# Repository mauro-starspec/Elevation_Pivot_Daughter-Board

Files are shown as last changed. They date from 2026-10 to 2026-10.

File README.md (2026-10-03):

# Elevation Pivot Daughter Board

KiCad 9 daughter board for the Starspec elevation/pivot controller.

## Current revision: P3

The schematic adds two isolated motor encoder interfaces while preserving both
SSI channels, two onboard 1206 thermistors, and all existing
controller functions. Port/Star names now apply
throughout the schematic, including brake, stepper, SSI, preset, and supply nets.
New signals use hierarchical labels; supplies use conventional power symbols.

One six-channel ISO7760F isolates both motor encoders' A/B/Z signals. Both
receivers share U105's 3.3 V supply from PS10; loss of PS10 disables both
feedback paths. The two 5 V encoder converters remain separate.

Device power switching belongs to external PSRB. Other systems already measure
battery voltage and device current. The P1 STR8 power/current and voltage
additions have been removed, along with the new one-shot encoder fuses and
external thermistor inputs. Existing brake current sensing is retained.

TH1 measures board temperature and TH2 the power area. Their passive dividers
use the existing U21 ADC's spare AIN2/3 inputs and U24 isolation. No extra sensor
ICs, regulator or I2C isolator are required. Temperature readings depend on the
brake supply. Firmware channel scheduling and conversion remain future work.

The PCB is unchanged and does not match the redesigned schematic. This is a
review revision, not a fabrication release. No firmware was changed.

## Open and review

Open [Elevation_Pivot_Daughter-Board.kicad_pro](Elevation_Pivot_Daughter-Board.kicad_pro)
in KiCad 9. Symbols and footprints are stored locally in the repository.

- [PROJECT_HANDOFF.md](PROJECT_HANDOFF.md): scope and next-session context.
- [SCHEMATIC_REDESIGN_P3.md](docs/SCHEMATIC_REDESIGN_P3.md): foundation review and current circuits.
- [REDESIGN_PLAN.md](docs/REDESIGN_PLAN.md): remaining review sequence.
- outputs/Pivot_Schematic_Review.pdf: local review export, ignored by Git.

Run `python tools/validate_pivot_schematic.py` to check connectivity, channel
renaming, original component values/footprints, encoder interfaces, ERC, and
the unchanged PCB hash. The two inherited Nucleo ERC exclusions remain.

Actual NEMA34 motor/encoder identity, supply demand, maximum frequency, and the
proposed custom DE9 harness must be verified. J20/J21 now use DE9 sockets;
plain-language captions identify the main components. The earlier HT23/ZAA reference
is unconfirmed for this hardware.

The original elevation project remains the firmware and bench-test reference.
The unchanged baseline PCB retains three known courtyard overlaps: H3/CN9,
H4/CN10, and H2/CN7.

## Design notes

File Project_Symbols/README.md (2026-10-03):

# Reviewed schematic symbols

`Electrical_Reviewed.kicad_sym` preserves the placed symbols' graphics, pin numbers, names and positions while correcting ERC electrical types. The schematic caches match this project-local library. It also preserves the PS1/PS5 and PS4 variants that previously differed from their library copies.

The September 2026 schematic cleanup checked these corrections against manufacturer documentation:

| Device | Correction and source |
|---|---|
| ISO6762 family | Ground pins 8/9 are power inputs. [TI](https://www.ti.com/lit/ds/symlink/iso6762-q1.pdf) |
| TPS7A2450 | Pins 1/2 are power inputs, 3 enable input, 4 NC, 5 power output. [TI](https://www.ti.com/lit/ds/symlink/tps7a24.pdf) |
| TPS1H100B | VS/GND inputs, control inputs, power outputs, CL/CS outputs and NC pins corrected. [TI](https://www.ti.com/lit/ds/symlink/tps1h100-q1.pdf) |
| LTC4364 | OUT is a voltage-sense input; FLT and ENOUT are open-drain outputs. [Analog Devices](https://www.analog.com/media/en/technical-documentation/data-sheets/ltc4364-1-4364-2.pdf) |
| R05CTE05S-R | Input/output supply types and DNC pin 10 corrected; SGND pins passive. One power-output pin represents each duplicated output rail, with its parallel pin passive. [RECOM](https://g.recomcdn.com/media/Datasheet/pdf/.fRwx-AHZ/.t138d12ed72264b8dfdd1/Datasheet-515/RxxCTExxS.pdf) |
| R-78HB6.5-0.5 | VIN/GND power inputs and VOUT power output. [RECOM](https://recom-power.com/pdf/Innoline/R-78HB-0.5.pdf) |
| SUM80090E, SSM3K361R | Passive discrete-MOSFET pin types. Pin numbering unchanged. [Vishay](https://www.vishay.com/docs/64434/sum80090e.pdf), [Toshiba](https://toshiba.semicon-storage.com/info/docget.jsp?did=36685&prodName=SSM3K361R) |
| STPS3H100, TPD1E10B09 | Passive diode/protection-device pin types. [ST](https://www.st.com/resource/en/datasheet/stps3h100.pdf), [TI](https://www.ti.com/lit/ds/symlink/tpd1e10b09.pdf) |
| J1, FL1 | Connector and common-mode choke pins are passive; neither generates power. |

In `NUCLEOH723ZG.kicad_sym`, hidden ground pins stacked on a visible power-input pin are passive to avoid unintended global aliases such as `GND_CN9`. Their visible counterpart remains a power input; pin numbering and connectivity are preserved.

The placed `NUCLEOH723ZG_Daughterboard_Interface` symbol represents CN7–CN11 only, in five contiguous units. CN12/CN3/CN4/CN15/CN16 are external Nucleo connectors outside this daughterboard interface. All 116 previously placed pins retain their electrical types, numbers, names and positions. Only symbols used by this project and their inherited bases are packaged; the original full-board symbol remains in Git history. The user confirmed the USB/E5V power-jumper arrangement; the schematic records it. No ERC exclusions or severity changes were introduced. Renumbering the five units changes the generated names of 67 unused U1 pin nets, with no connection changes.

Twelve added PWR_FLAGs declare the existing J1 supply/return entries, the protected battery rail, Q16-referenced GND_FLOAT, the filtered PS4 return, post-F1/F2 brake supplies and post-FB1/FB2/FB3 rails. They describe source paths for ERC; they do not bypass fuses, filters, isolation or Q16 and do not assert that switched supplies are always on.

Verification: ERC 61 → 0, identical membership of all 318 nets, zero PCB opens and zero schematic-parity findings. The PCB is unchanged. This review does not qualify power capacity, component stress or thermal behavior; the Nucleo jumper must match the selected power source.

Project library tables use relative paths. Used standard KiCad definitions and vendor libraries are included alongside the reviewed variants; unused symbols were omitted. Standard KiCad library sources: https://gitlab.com/kicad/libraries/kicad-symbols and https://gitlab.com/kicad/libraries/kicad-footprints. Optional 3D models are not bundled.

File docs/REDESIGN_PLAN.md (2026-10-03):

# Pivot daughter-board review plan

Current scope: P3, 2026-10-03. Two motor encoders supplement the existing SSI
channels. Both onboard temperature sensors remain, now as passive 1206 thermistors. Port/Star naming
covers the entire schematic. PSRB handles external
device power control; voltage and device-current measurement exist elsewhere.
P1 power distribution, current/voltage monitoring, and external thermistor
inputs are superseded and removed. Onboard temperature remains in scope.

## Completed schematic work

- Add two protected, isolated differential A/B/Z receiver interfaces.
- Consolidate their six forward signals into U101 ISO7760F, with shared 3.3 V
  receiver power from PS10/U105; remove the second isolator and logic regulator.
- Allocate TIM2/TIM3 quadrature inputs and two index inputs.
- Preserve the controller, brake sensing, drive controls, SSI, and CAN.
- Restore the baseline J1 inlet; use spare ADC inputs for two onboard thermistors.
- Remove the added one-shot encoder fuses.
- Apply Port/Star names to all channel signals and power nets.
- Use hierarchical signal labels and conventional power symbols.
- Add TH1/TH2 on the existing ADC sheet, reusing its supply and isolation.

## Remaining schematic review

1. Identify the actual NEMA34 motor/encoder assemblies and installed cables.
2. Confirm DE9 parts, pinout, mating views, shield bonds, and cable impedance.
3. Check encoder current, converter overload behavior, protected-bus load,
   voltage limits, and temperature derating with the external power system.
4. Check maximum frequency, bias margin, input filtering, timer-wrap handling,
   and index/reference strategy.
5. Confirm minimum electronics temperature, enclosure thermal control, and
   placement/calibration of the two onboard sensors.

Run `python tools/validate_pivot_schematic.py` after schematic changes.
See [SCHEMATIC_REDESIGN_P3.md](SCHEMATIC_REDESIGN_P3.md) for implemented details.

PCB synchronization/layout requires a separate request. Later checks include
return paths, isolation spacing, connector mechanics, DRC, manufacturing outputs,
and first-article testing. Firmware must use the verified encoder resolution
and channel mapping. Temperature firmware must add AIN2/3 with per-channel
gain/scaling, curve 1010 conversion and calibration, retaining brake sampling cadence.

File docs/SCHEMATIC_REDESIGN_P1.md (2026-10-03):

# P1 schematic redesign

**Historical revision, superseded by P2 on 2026-10-03.** The user removed the
added STR8 power/current and voltage circuits because other
systems provide the required functions, including PSRB power control.
The current schematic adds motor encoders, retains both onboard temperature
sensors, and uses Port/Star throughout. External thermistor inputs are omitted.
See [P2](SCHEMATIC_REDESIGN_P2.md); do not use the P1 requirements below for new work.

Date: 2026-10-03. Scope: schematic only. The PCB is still the original baseline
and does not represent these circuits. P1 is an engineering review revision,
not a fabrication release.

## Decisions from this session

Mauro confirmed that both existing SSI channels must remain, with two motor
encoders added. D-sub connectors are preferred. He identified the motors as
NEMA34; that conflicts with the previous HT23-553D-ZAC identification. The actual
motor and encoder part numbers, resolution, supply demand and harness therefore
remain unverified. A NEMA frame size does not determine electrical current.

The new encoder circuits assume 5 V differential A/B/Z. Do not connect an
unverified encoder or legacy cable to the proposed connectors.

## What changed

| Sheet | Added circuitry |
|---|---|
| `Pivot_Encoder_Port` | HD15 connector, A/B/Z termination, bias and ESD protection; quad receiver; three-channel isolator; dedicated encoder supply |
| `Pivot_Encoder_Star` | Same circuit for Star |
| `Pivot_STR8_Power` | Main battery inlet, two fused raw-battery branches, two Hall current sensors, external regeneration-clamp connection, shield/chassis connection |
| `Pivot_Monitoring` | Field 3.3 V rail, isolated I2C, second ADC, raw and protected bus dividers and input protection |
| `Pivot_Temperature` | Two TMP117 sensors and two protected external thermistor inputs |

The STM32 sheet connects six previously unused connector positions to the new
encoder outputs. U21 AIN2/AIN3 now receive STR8 currents. The existing MCU I2C
bus also connects to the new monitoring circuits. Existing SSI, brake, step,
direction, disable, fault, CAN and supply-conversion circuits are retained.

J8 is the new main battery inlet. J1 pins 1/2 are intentionally disconnected
and marked NC; J1 pins 3/4 still accept the separate brake supply. This prevents
the old smaller connector from becoming the intended two-drive battery inlet.
The harness must change accordingly.

## MCU allocation

| New signal | Nucleo connection | MCU pin | Function |
|---|---|---|---|
| Port A | CN7 pin 10 / D13 | PA5 | TIM2_CH1, AF1 |
| Port B | CN7 pin 15 / D23 | PB3 | TIM2_CH2, AF1 |
| Port Z | CN9 pin 16 / D57 | PE4 | EXTI4 input |
| Star A | CN7 pin 1 / D16 | PC6 | TIM3_CH1, AF2 |
| Star B | CN7 pin 11 / D21 | PC7 | TIM3_CH2, AF2 |
| Star Z | CN9 pin 22 / D60 | PE3 | EXTI3 input |

Use SWD debugging and disable SWO trace on PB3. PA5 also connects to the
Nucleo D13 LED control circuit; its loading must be included in signal testing.
PE6 was deliberately avoided because it is used by the existing Star fault
input through CN10 pin 28. Nucleo alternate connector positions are not
independent MCU pins.

TIM2 is 32-bit and TIM3 is 16-bit. Firmware must extend the Star counter across
wraps and handle direction correctly. Maximum encoder frequency, digital input
filtering and index capture latency must be checked after motor speed and
encoder resolution are known. No firmware was changed.

Sources: [STM32H723 datasheet](https://www.st.com/resource/en/datasheet/stm32h723zg.pdf),
[MB1364 user manual](https://www.st.com/resource/en/user_manual/um2407-stm32h7-nucleo144-board-stmicroelectronics.pdf),
[H723 Nucleo schematic](https://www.st.com/resource/en/schematic_pack/mb1364-h723zg-e01_schematic.pdf).

## Encoder circuits and harness

Each channel uses AM26LV32EIDR followed by ISO7730FDWR. The receivers and encoder
power reference `-BATT`; the isolator outputs use `+3V3_STM32` and `GND_STM32`.
No encoder return connects directly to the MCU ground.

Each differential pair has a provisional 120 ohm termination and 560 ohm
pull-up/pull-down bias. Ignoring receiver loading, disconnected-cable bias is
3.3 x 120 / (560 + 120 + 560) = 0.319 V. At 3.0 V with adverse 1% resistor
tolerances it is about 0.285 V before receiver loading. The termination in
parallel with the bias path presents about 108 ohms differential load.
Validate bias margin with receiver loading and confirm cable impedance and
encoder drive capability before freezing values. A shorted pair is not a
guaranteed valid state or a detected cable fault.

The three ESD arrays per encoder are TPD2E2U06QDBZRQ1, with pins 1/2 on the
signals and pin 3 on `-BATT`. Their unidirectional clamps assume signals stay
near the supplied 0-to-5 V field domain. Test ESD and ground-offset behavior at
the complete connector; a component ESD rating is not a system test result.

Each encoder has a dedicated R-78HB5.0-0.5 supply from `+BATT_Prot`, a provisional
0.5 A output fuse, and a local 3.3 V receiver regulator. Input capacitance must
remain at least 3.3 uF at the maximum applied DC voltage. Check converter
minimum-load behavior, availability, output tolerance, cable voltage drop and
temperature derating. The converter's 72 V input limit constrains the protected
bus clamp. Budget up to roughly 5 W total output for these two supplies before
losses, although actual encoder consumption is unknown.

Proposed board connector pinout, J20/J21:

| Pin | Signal |
|---|---|
| 1 | Fused +5 V |
| 2 | Field return, -BATT |
| 3 / 4 | A+ / A- |
| 5 / 6 | B+ / B- |
| 7 / 8 | Z+ / Z- |
| 9 | Additional field return |
| 10-15 | NC |
| Shell | PIVOT_CHASSIS |

This is a proposed **custom harness** mapping, not the Applied Motion cable
pinout. Connector gender, mating view, footprint and exact MPN are release
holds. Do not substitute a two-row DA15 for the three-row HD15 symbol.
J12 provides the new shield/chassis termination. C188 couples it to field
return; R172 is a DNP direct-bond option. Confirm the system chassis bond and
compatibility with the retained connector shells, which use the old grounding
arrangement. Do not populate ground bonds without that review.

Sources: [receiver datasheet](https://www.ti.com/lit/ds/symlink/am26lv32e.pdf),
[isolator datasheet](https://www.ti.com/lit/ds/symlink/iso7730.pdf),
[ESD array datasheet](https://www.ti.com/lit/ds/symlink/tpd2e2u06-q1.pdf),
[RECOM supply datasheet](https://recom-power.com/pdf/Innoline/R-78HB-0.5.pdf).

## STR8 power and current measurement

Both branches start at raw `+BATT`, ahead of the LTC4364. Each branch passes
through a 7 A fast fuse and an ACS725LLCTR-20AB-T before its drive connector.
Both primary input pins and both primary output pins are connected. Drive
returns go directly to `-BATT`. The LTC4364 current limit has not been changed.

The 7 A fuse value follows the manufacturer's STR8 recommendation. It is not
a measurement of operating current. The manual also explains why phase
current and DC input current differ. Without the motor winding data, load,
speed and drive settings, actual average and peak supply currents cannot be
calculated reliably. Two 7 A branches give a provisional 14 A distribution
design basis, plus the protected board loads; a fuse does not clamp current to
its nominal rating.

The ±20 A range is provisional and gives more transient headroom than ±10 A.
At nominal 3.3 V the sensitivity is 66 mV/A and zero-current output is 1.65 V.
At 7 A, typical conductor dissipation is 7² x 0.0012 = 59 mW per sensor.
Fault/inrush pulse survival still needs the fuse let-through and Hall conductor
limits checked together. The board has no validated copper-current rating yet.

Sensor electronics use a new 3.3 V regulator in the existing brake ground
domain. Their isolation barriers separate the battery conductor from those
electronics. U21 remains at its existing 5 V supply and 0x48 I2C address.
AIN0/1 still measure brake currents; AIN2/3 measure Port/Star STR8 current.
The Hall FILTER capacitors are 10 nF and output RC filters are 4.7 kΩ/1 uF
(about 34 Hz). Use PGA ±4.096 V. Nominal conversion is:

`current_A = (signed_code * 0.000125 - calibrated_zero_V) / calibrated_sensitivity_V_per_A`

The nominal quantization step is about 1.89 mA; this is not sensor accuracy.
Hall offset/noise, supply tolerance and temperature dominate. A 1% change in
sensor supply alone moves the nominal zero by about 0.25 A equivalent.
Calibrate zero and gain, and do not use this multiplexed ADC as fast overcurrent
protection. The Hall supply is not independently measured in P1.

J8-J11 electrically select Phoenix 1714971 terminals, rated nominally 32 A.
Their manufacturer footprint remains unassigned pending mechanical review.
F20/F21 require exact fast-fuse and holder MPNs, a DC voltage rating of at least
125 V and adequate battery fault-current breaking capacity. Those footprints
are deliberately unassigned. Final fuse coordination, cable gauge, connector
derating and upstream pack protection remain open.

J11 is only a connection for an external regeneration clamp; a clamp is not
implemented on this board. Regeneration can flow back through each sensor and
fuse to the battery while the path is closed. A BMS or emergency disconnect
can remove that sink. Specify an energy-rated clamp and disconnect strategy
before energizing the redesign. The clamp threshold must exceed maximum charged
battery voltage and stay below the drive limit, including tolerances.
Reverse-polarity protection for these raw branches is external and mandatory;
the existing LTC4364 protection does not cover them. Added drive bulk capacitance
is deferred until inrush and regeneration energy are known.

Sources: [STR4/8 hardware manual, revision L](https://applied-motion.s3.amazonaws.com/documents/Manuals/STR4-8%20Hardware%20Manual%20920-0030L_0.pdf),
[ACS725 datasheet](https://www.allegromicro.com/-/media/files/datasheets/acs725-datasheet.pdf),
[Phoenix 1714971](https://www.phoenixcontact.com/us/products/1714971/pdf).

## Voltage and temperature measurement

U142 is an ADS1115 in the battery field domain. A separate ISO1540 links it to
the existing MCU I2C bus. ADDR connects to SDA for address 0x4A. U142 reads raw
battery, protected bus and the two thermistor inputs. U140 supplies the new
field 3.3 V rail. Existing MCU pull-ups remain; the new field bus has its own
4.7 kΩ pull-ups. Start at 100 kHz and verify bus capacitance and low-level
thresholds with both isolation branches connected. Do not assume arbitrary
multi-master or clock-stretching operation through parallel side-1 isolators.

Each voltage divider is three 100 kΩ, 0.1% upper resistors and a 10 kΩ, 0.1%
lower resistor. A further 10 kΩ and 100 nF filter precede the ADC. BAT54S
diodes clamp to the field rails. R192 bleeds the field rail when unpowered,
limiting back-power from the high-value dividers. The 90 V measurement envelope
is a provisional diagnostic range, not permission to apply 90 V to the drives
or converters. Upstream surge energy and clamp voltage still require review.

| Applied bus voltage | Ideal ADC voltage |
|---|---|
| 48 V | 1.548 V |
| 75 V | 2.419 V |
| 90 V | 2.903 V |

At PGA ±4.096 V, nominal bus voltage is `signed_code * 0.000125 * 31`.
Use at least 20 ms power-up settling. Calibrate the assembled divider: ADC input
loading, resistor tolerances, clamp leakage and temperature affect this ideal
ratio. In particular, BAT54S leakage can be material with a high-impedance
divider. The design does not claim precision voltage accuracy across temperature.

U143 is a TMP117 on MCU ground, with ADD0 tied high for 0x49. It measures board
temperature away from local heat sources. U144 is another TMP117 on field
ground, ADD0 tied to field SCL for 0x4B; it measures a power-area hot spot.
Both ALERT outputs are NC and software polls temperatures. The exposed-pad
ground connection assumes assembly followed by calibration; review TI's
mechanical-stress guidance before finalizing the paste/thermal-pad treatment.

J22/J23 accept insulated 10 kΩ NTC probes. Pull-ups, series resistors, shunt
capacitors, ESD protection and rail clamps are provided. An absent probe reads
high and a shorted probe reads low. Choose probe beta, accuracy and cable
length before writing conversion and plausibility limits. These inputs do not
measure motor winding temperature unless the probe installation supports it.

Sources: [ADS1115 datasheet](https://www.ti.com/lit/ds/symlink/ads1115.pdf),
[ISO1540 datasheet](https://www.ti.com/lit/ds/symlink/iso1540.pdf),
[TMP117 datasheet](https://www.ti.com/lit/ds/symlink/tmp117.pdf),
[TLV755P datasheet](https://www.ti.com/lit/ds/symlink/tlv755p.pdf).

## Verification and release holds

Run `python tools/validate_pivot_schematic.py`. The audit exports the current
netlist and ERC report, compares retained baseline net membership, checks new
interfaces and isolation-domain assignments, and verifies the PCB hash.
The baseline snapshot is tied to commit `e0909c8`. Generated reports and the
review PDF are in `outputs/` and are ignored by Git.

The project already contains two Nucleo ERC exclusions (missing unit and missing
power unit). They have not been added to or relaxed. KiCad CLI counts these
in its summary even when its detailed report contains zero reported findings.

Before schematic release, resolve:

1. Actual motor/encoder identity, supply current, cable pinout, resolution and maximum frequency.
2. Exact HD15 parts and mating harness; power-terminal, fuse and fuse-holder footprints.
3. Battery maximum voltage, available short-circuit current, upstream fuse, polarity protection and regeneration/disconnect behavior.
4. Measured STR8 input current, acceleration peaks and inrush; then finalize Hall range, filters and fuse coordination.
5. Minimum electronics temperature and thermal control. P1 is not qualified for -50 °C; several selected parts start at -40 °C.
6. Added protected-bus power budget, converter/clamp compatibility and temperature derating.
7. Required measurement accuracy, calibration and external-probe locations.

Layout, routing, PCB parity/DRC, thermal validation, harness testing and bench
qualification have not been performed. No claim of hardware safety or successful
operation follows from ERC or netlist checks.

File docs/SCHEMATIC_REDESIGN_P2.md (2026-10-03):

# P2 schematic - motor encoders, onboard temperature, and Port/Star naming

**Historical revision:** P3 supersedes the temperature circuit, label
presentation, HD15 connector choice, and separate ISO7730F isolators below. See
[SCHEMATIC_REDESIGN_P3.md](SCHEMATIC_REDESIGN_P3.md) for the current DE9 map.
The encoder MCU pin allocations remain applicable.

Date: 2026-10-03. Schematic only; PCB and firmware unchanged.

## Scope

Two motor encoder interfaces supplement the retained SSI channels. External
systems already monitor battery voltage and device current; PSRB can remotely
switch device power. P1's STR8 power/current and voltage sheets have been
removed. Both onboard temperature sensors are retained; their earlier removal
was an assistant error, now corrected. J1 has its original supply connections. U21 still
measures brake currents on AIN0/1; AIN2/3 are unused. The previous current-sensor
range discussion is superseded by removal of those sensors.

F10/F11, the new one-shot encoder fuses, were also removed. Dedicated 5 V
converters now feed the encoder connectors directly. Verify converter overload
behavior, cable ratings, and upstream protection with the external system;
remote power cycling alone does not specify current limiting. Existing baseline
protection is retained.

## Whole-schematic naming and labels

| Previous name | P2 name |
|---|---|
| LH_* | PORT_* |
| RH_* | STAR_* |
| +5V_ENC_L / +5V_ENC_R | +5V_ENC_PORT / +5V_ENC_STAR |
| +6.5V_ENC_L / +6.5V_ENC_R | +6.5V_ENC_PORT / +6.5V_ENC_STAR |

The migration covers root sheet pins, child-sheet ports, local/global signal
labels, power-symbol instances, cached definitions, and the project power
library. It preserves references, part numbers, component values, and footprints.
KiCad's left/right text-alignment settings are unrelated to channel naming.

New encoder signals use hierarchical ports and local labels. Supplies use
arrow/ground power symbols. The longer preset labels were moved into open space
on the STM32 sheet. Electrical verification compares connected component pins
against the baseline independently of names, detecting swaps, splits, or merges.

## MCU allocation

| Signal | Nucleo connection | MCU function |
|---|---|---|
| PORT_ENC_A | CN7 pin 10 / PA5 | TIM2_CH1 AF1 |
| PORT_ENC_B | CN7 pin 15 / PB3 | TIM2_CH2 AF1 |
| PORT_ENC_Z | CN9 pin 16 / PE4 | EXTI4 |
| STAR_ENC_A | CN7 pin 1 / PC6 | TIM3_CH1 AF2 |
| STAR_ENC_B | CN7 pin 11 / PC7 | TIM3_CH2 AF2 |
| STAR_ENC_Z | CN9 pin 22 / PE3 | EXTI3 |

Disable SWO on PB3 and use SWD. Verify loading from the Nucleo PA5 LED-control
input. TIM2 is 32-bit; TIM3 is 16-bit and needs firmware wrap extension. PE6
remains the Star drive fault input. Maximum frequency, filtering, and index
latency depend on actual encoder resolution and motor speed.

## Encoder circuits

Each channel uses an AM26LV32EIDR receiver and ISO7730FDWR three-channel isolator.
Field electronics reference -BATT. The isolator output uses +3V3_STM32 and
GND_STM32; those grounds remain separate.

Each A/B/Z pair has a provisional 120 ohm, 1%, 0.5 W termination and two 560 ohm
bias resistors. Nominal disconnected-cable bias is about 0.319 V before receiver
loading. Confirm cable impedance, drive capability, and bias margin. A shorted
pair does not guarantee a defined logic state. TPD2E2U06QDBZRQ1 arrays provide
signal ESD protection at the connectors.

R-78HB5.0-0.5 converters supply the new encoders from +BATT_Prot. Their 5 V outputs
also feed TLV75533 regulators for the receiver and field side of each isolator.
The new rails are +5V_MOTOR_ENC_PORT/STAR and +3V3_MOTOR_ENC_PORT/STAR, distinct
from the retained SSI supplies. Verify effective input capacitance, total
protected-bus load, the converter's 72 V input limit, minimum-load behavior,
temperature derating, overload behavior, and actual encoder consumption.

Proposed custom J20/J21 HD15 socket mapping:

| Pin | Signal |
|---|---|
| 1 | Dedicated +5 V motor-encoder supply |
| 2, 9 | Field return, -BATT |
| 3 / 4 | A+ / A- |
| 5 / 6 | B+ / B- |
| 7 / 8 | Z+ / Z- |
| 10-15 | NC |
| Shell | PIVOT_CHASSIS |

The user identified NEMA34 motors; the older HT23/ZAA reference is unconfirmed.
This proposed mapping is not approved for direct mating to an existing cable.
Confirm actual hardware and both mating views.

J12 provides the chassis connection on the Port encoder sheet. C188 couples
the shell net to field return; R172 is an unpopulated direct-bond option. The
chassis power flag represents the external chassis connection at J12. Check
bonding against the retained connector-shell arrangement before assembly.

## Onboard temperature retained

U143 and U144 are TMP117AIDRVR devices, restored with their original electrical
roles. U143 is a board-ambient proxy on the MCU supply/ground, address 0x49
(ADD0 tied high). U144 measures the power area on field ground, address 0x4B
(ADD0 tied to field SCL). Both ALERT pins are unused; firmware polls temperatures.
The exposed pads connect to each sensor's local ground. Review assembly stress,
calibration, and thermal placement before layout.

The temperature sheet also contains U140 (TLV75533 field 3.3 V supply), U141
(ISO1540 isolated I2C), R180/R181 (field pull-ups), and local decoupling. The MCU
side shares the original I2C bus and R67/R68 pull-ups with the brake ADC at 0x48.
The field bus and MCU bus remain isolated. Begin at 100 kHz and verify rise time
and low-level margins on both isolation branches.

No voltage/current ADC, divider, or external thermistor input is restored.

## Verification

Run `python tools/validate_pivot_schematic.py`. It exports the KiCad netlist and
ERC report and checks retained pin groups, exact channel renaming, original
component values/footprints, six encoder signals, supplies, isolation domains,
restored J1/U21 connections, both temperature sensors and their addresses,
isolated field supply/bus, and absence of removed P1 components. It also checks
the unchanged PCB hash and the unchanged two inherited Nucleo ERC exclusions.
Baseline data is tied to commit e0909c8.

Final P2 audit: 306 retained baseline net groups preserved, 32 explicit
connection checks passed, original component values/footprints preserved,
zero reported ERC findings with the two existing exclusions unchanged, and
an unchanged PCB SHA-256.

Reports and the 12-sheet review PDF are in outputs/. P1 source before cleanup
is recoverable under _work/before_p2_cleanup/. Both folders are ignored by Git.
The cleanup does not establish layout parity, environmental qualification, or
successful operation on hardware.

## References

- [STM32H723](https://www.st.com/resource/en/datasheet/stm32h723zg.pdf)
- [Nucleo MB1364 manual](https://www.st.com/resource/en/user_manual/um2407-stm32h7-nucleo144-board-stmicroelectronics.pdf)
- [AM26LV32E](https://www.ti.com/lit/ds/symlink/am26lv32e.pdf)
- [ISO7730](https://www.ti.com/lit/ds/symlink/iso7730.pdf)
- [TPD2E2U06-Q1](https://www.ti.com/lit/ds/symlink/tpd2e2u06-q1.pdf)
- [RECOM R-78HB](https://recom-power.com/pdf/Innoline/R-78HB-0.5.pdf)
- [TLV755P](https://www.ti.com/lit/ds/symlink/tlv755p.pdf)
- [TMP117](https://www.ti.com/lit/ds/symlink/tmp117.pdf)
- [ISO1540](https://www.ti.com/lit/ds/symlink/iso1540.pdf)

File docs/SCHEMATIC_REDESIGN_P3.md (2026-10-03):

# P3 - passive onboard temperature and drawing cleanup

2026-10-03. Schematic only. Supersedes P2 temperature circuitry and header-label
presentation; retains its encoder interfaces and Port/Star channel mapping.
Subsequent drawing update: DE9 connectors and component-role captions, while
preserving the user's schematic presentation edits.

## Foundation reviewed

Reviewed the original elevation project's schematic and engineering README,
the original controller firmware's pin definitions and ADS1115 acquisition,
and the frozen baseline connectivity/component records at e0909c8.

- The daughter board carries control and feedback, not motor-phase wiring.
- Two SSI absolute-encoder channels remain; two motor A/B/Z interfaces supplement them.
- The original isolation domains are intentional: -BATT, GND_STM32, GND_BRAKE,
  GND_CAN, GND_FLOAT, and the filtered PS4 input return. GND_FLOAT returns through
  Q16; the PS4 input return must not bypass FL1. No domains are joined by this change.
- Original U21 is an ADS1115BQDGSRQ1 at 0x48, powered from +5V_BRAKE. U24 already
  isolates its bus from the MCU. AIN0/1 measure brake current; AIN2/3 were spare.
- The original firmware samples only AIN0/1, with a fixed +/-4.096 V scale.
  Passive sensors can use its spare inputs; another ADC, regulator and isolator
  are unnecessary for this function.
- Existing physical-header and MCU-unit signal ports are hierarchical labels
  with 1.27 mm text. New encoder ports now follow that convention at both ends.
- External systems measure battery/device current and voltage; PSRB controls
  device power. Those functions are not added to this daughter board.

## Two onboard thermistors

TH1 and TH2 are on ADS1115.kicad_sch, alongside the existing converter. The
separate temperature sheet and added U140/U141/U143/U144 are removed. The sensors
remain mounted on the board; there are no external temperature connectors.

| Function | Sensor | Divider / filter | ADC input |
|---|---|---|---|
| Board-temperature proxy | TH1 | R180 / R182 / C190 | U21 AIN2, pin 6 |
| Power-area temperature | TH2 | R181 / R183 / C191 | U21 AIN3, pin 7 |

Selected sensor: TDK B57621C5103J062, a 10 kohm NTC, +/-5% at 25 C, with R/T
characteristic 1010. The 1206 body is approximately 3.2 x 1.6 mm with two exposed
solder terminations, using the existing R_1206_3216Metric footprint. It has no
hidden thermal pad. Its specified operating range is -55 to +125 C; this does
not extend the rating of the existing ADC or the rest of the board.

Each circuit is +5V_BRAKE -> NTC -> 10 kohm, 0.1% -> GND_BRAKE, with 1 kohm
series resistance and 100 nF at the ADC input. Only eight passive parts are added
for both sensors. The divider output rises with temperature. At nominal 5 V:

| Temperature | Nominal ADC voltage, before small input loading |
|---|---|
| -40 C | 0.224 V |
| 25 C | 2.500 V |
| 85 C | 4.391 V |

Use R_NTC = R_fixed * (V_excitation / V_ADC - 1) and the manufacturer's curve
1010 to convert resistance. These are nominal values, not accuracy guarantees:
thermistor tolerance, excitation tolerance/drift, ADC loading and thermal
placement affect the result. Calibrate the excitation and temperature response.
Maximum nominal thermistor dissipation is 0.625 mW at R_NTC = 10 kohm; verify
self-heating under the actual enclosure/low-pressure conditions.

Both sensors electrically belong to GND_BRAKE even when placed near a heat
source in another domain. Preserve isolation clearances and do not bond a
sensor pad to unrelated copper. TH1 should be away from local heat sources;
TH2 should be near the selected power hot spot. Placement waits for layout.
Readings require the brake supply and are invalid when it is off.

## Firmware follow-through, not implemented here

Keep the existing brake channels at +/-4.096 V and their existing scaling.
Configure temperature channels for +/-6.144 V: nominal 187.5 microvolt/code.
The PGA range does not allow ADC pin voltages outside its supply rails.
Expand the two-channel scheduler and per-channel scale handling; sample
temperature slowly while retaining the required brake-current acquisition
cadence. Discard readings on supply loss and allow filter settling after power-up.
Detect near-rail sensor faults instead of converting them to plausible temperatures.
An open high-side NTC pulls the input low; a short pulls it near the supply.
Temperature accuracy and fault thresholds need bench calibration.

No firmware files were changed. No new I2C addresses, pull-ups or bus branches
are introduced. Existing U21 and U24 still communicate over the original I2C bus.

## Drawing and connectivity

All six motor-encoder signals now use matching hierarchical input labels at
the physical Nucleo sockets and MCU units. CN9 index labels align with the
adjacent SSI labels. Local labels remain appropriate for nets confined to a
sheet, such as the two thermistor outputs; they are not inter-sheet ports.
New local labels use the existing 1.27 mm text size. Supplies retain power symbols.

Validation compares original pin groups independently of their renamed net
names, and checks the exact Port/Star migration. Only the twelve allocated
MCU/socket pins and two formerly unused ADC pins are exempt from the frozen
baseline; their new connections are explicitly checked. All original component
values/footprints, the PCB hash, and the two inherited ERC exclusions are checked.
Header label type and size are checked to prevent the screenshot mismatch.

Run `python tools/validate_pivot_schematic.py`. Reports and the 11-page review
PDF are in outputs/. The pre-P3 files are recoverable in _work/before_p3/.
These checks establish schematic consistency, not hardware qualification.

Final P3 result: 304 original net groups preserved, 31 explicit connection checks
passed, and zero reported ERC findings with two inherited exclusions unchanged.
A separate comparison with the pre-P3 netlist preserved all 357 retained pin
groups, including the complete added encoder circuits. CN7/CN9 and the ADC
sheet were checked in the rendered PDF. The PCB SHA-256 is unchanged.

## Open encoder decisions

Actual NEMA34 encoder identity, supply consumption, A/B/Z electrical interface,
resolution, maximum frequency and existing D-sub harness remain unverified.
The custom DE9 pinout remains a proposal. NEMA frame size does not determine
encoder pinout or drive current. See the retained encoder sections in the P2
report and PIVOT_ENCODER_INTERFACE.md. Do not treat the earlier HT23/ZAA example
as the installed hardware. Existing SSI, brakes, CAN and drive-control circuits
remain intact; PCB and original firmware remain unchanged.

## DE9 and component descriptions

J20/J21 now use Connector:DE9_Socket_MountingHoles, with the same right-angle
DE9 footprint family as the existing connectors on this board. This updates
the schematic footprint assignment only; the PCB is unchanged. Existing pins
1-9 keep their assignments and the six unused HD15 contacts are removed.

| DE9 contact | Function |
|---|---|
| 1 | Dedicated +5 V motor-encoder supply |
| 2, 9 | Field return, -BATT |
| 3, 4 | A+, A- |
| 5, 6 | B+, B- |
| 7, 8 | Z+, Z- |
| Shell / pad 0 | PIVOT_CHASSIS |

The earlier HD15 cable reference does not establish DE9 harness compatibility.
The manufacturer's eventual connector and cable drawings must match this map.
No power supplies were consolidated in this update.

Forty-five short text captions identify the main receivers, isolators,
regulators, power converters, ADC, CAN transceiver, brake switches, protection
devices and filter. They are drawing text, not signal labels or part values.
The user's component positions and visual edits are retained; only connector
stub geometry changes where required by the DE9 symbol. A snapshot of the
user's files before this update is in _work/before_de9_names/.

Update verification: 2,913 pre-existing drawing items are unchanged, excluding
the intentional connector edits. All 347 retained net groups match the user's
saved schematic at the start of this update; only twelve unused HD15 contacts
were removed. The baseline checks still pass with zero reported ERC findings
and the PCB hash unchanged. The captions were checked in the rendered review.

## Shared six-channel encoder isolation

The latest update replaces U101/U111 ISO7730F with one ISO7760FDWR U101.
All six channels run from the field receivers toward the MCU: Port A/B/Z
use inputs 2/3/4 and outputs 15/14/13; Star A/B/Z use inputs 5/6/7 and
outputs 12/11/10. The MCU allocation and DE9 pinout remain unchanged.
The device retains the SOIC-16W footprint. The F variant defaults outputs
low on loss of field-side power while the MCU-side supply remains powered.

U105 now supplies both receivers, their bias networks, and U101's field side
on +3V3_MOTOR_ENC. U115 and C143/C144/C146/C147 are removed with U111.
U101 pins 1/8 use +3V3_MOTOR_ENC/-BATT; pins 16/9 use
+3V3_STM32/GND_STM32. These isolation domains remain separate. No regulator
outputs are paralleled. C115/C145 bypass the receivers and C116/C117 bypass
the two isolator supplies; C114 remains U105's output capacitor.

PS10 and PS11 remain separate 5 V encoder converters. PS10 also supplies
U105, so its loss disables both feedback paths even if PS11 remains powered.
Encoder current and converter margin still require the actual encoder data.

Star receiver outputs cross the hierarchy into U101 on the Port sheet.
All six MCU-side test points are together there. The user's six root-sheet
MCU wires are preserved. Source before this update is saved under
_work/before_shared_isolator/. Current validation: 304 baseline net groups,
42 explicit connection checks, zero reported ERC findings with the two
inherited exclusions unchanged, and unchanged PCB hash. The root and both
encoder sheets were inspected in the refreshed PDF.
Comparison against the user's saved schematic preserves 339 retained pin
groups after accounting for the intentional shared-rail merge and replaced
parts. All 35 original root wires are unchanged, and every other child sheet
is byte-identical to the snapshot.

## Primary component references

- [TI ISO7760 datasheet](https://www.ti.com/lit/ds/symlink/iso7760.pdf): six forward channels, pin map, supply range and F-variant default-low behavior.

- [TDK 1206 NTC datasheet, B57621C5, February 2019](https://product.tdk.cn/system/files/dam/doc/product/sensor/ntc/chip-ntc-thermistor/data_sheet/50/db/ntc/ntc_smd_standard_series_1206.pdf), pages 2 and 4: package, ordering code, ratings and curve 1010.
- [TI ADS1115-Q1 datasheet](https://www.ti.com/lit/ds/symlink/ads1115-q1.pdf): input limits, gain ranges and input impedance.

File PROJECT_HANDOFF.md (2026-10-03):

# Project handoff - Elevation Pivot Daughter Board

Last updated: 2026-10-03. Current revision: **P3, encoders and passive onboard temperature**.

## Current scope

Retain the working controller and both existing SSI channels. Add two isolated
motor incremental-encoder interfaces and retain two onboard temperature
sensors as simple 1206 thermistors. Work is schematic only; the PCB and
firmware remain unchanged.

The user confirmed that other systems already measure battery voltage and
device current. PSRB can remotely switch device power off and on. P2 removes
the P1 STR8 power distribution, ACS725 sensors, and battery-voltage sensing.
The user explicitly retained the onboard temperature sensors; their earlier
removal was an assistant error, now corrected. External thermistor inputs remain
omitted. Do not restore the removed power/voltage/current functions from P1.

The new one-shot encoder fuses were also removed because they cannot be
replaced during balloon flight. Dedicated encoder supplies remain. Their
overload behavior and upstream protection still need system review; remote
cycling alone does not establish a current limit.

Existing brake current sensing, protection, supply conversion, CAN, stepper
controls/faults, preset signals, and both SSI interfaces are retained. J1 has
its original battery and separate brake-supply connections. U21 AIN2/3 are
now connected to TH1/TH2 on the ADC sheet.

## Naming throughout the schematic

Port replaces the former left/LH channel; Star replaces the former right/RH
channel. This covers all signal labels, hierarchical sheet pins, and supply
nets, including brakes, stepper drives, SSI, and preset circuitry.

Existing SSI supplies are +5V_ENC_PORT, +5V_ENC_STAR, +6.5V_ENC_PORT, and
+6.5V_ENC_STAR. New supplies use +5V_MOTOR_ENC_PORT/STAR and
the shared +3V3_MOTOR_ENC logic rail so they remain distinct from SSI.

The original project, firmware, and unchanged PCB retain historical naming.
Header and MCU-unit encoder signals both use the original hierarchical
label style and 1.27 mm text. Local labels identify internal sheet nets. Supplies use
conventional arrow/ground power symbols.

## Encoder assumptions and implementation

The user identified NEMA34 motors. Earlier notes identified HT23-553D-ZAC,
which conflicts with that description. Actual motor/encoder part numbers,
supply demand, resolution, and installed cable wiring remain unverified.
Earlier HT23/ZAA data is reference material only.

P3 retains the assumed 5 V differential A/B/Z encoders. The user selected DE9
sockets for J20/J21, matching the connector family already used on this board.
Do not assume the proposed pinout matches an existing cable.

DE9 pinout: 1 = +5 V; 2 and 9 = return; 3/4 = A+/A-; 5/6 = B+/B-;
7/8 = Z+/Z-; shell = PIVOT_CHASSIS. Pins 1-9 retain their previous assignments.
The latest drawing update preserves the user's visual edits and adds short,
plain-language role captions beside the main ICs, converters and filter.
The two 5 V converters remain separate; the 3.3 V receiver supply is now shared.

Each interface uses an AM26LV32E receiver, termination/bias, ESD protection,
and a dedicated R-78HB5.0-0.5 encoder supply. One ISO7760FDWR (U101) isolates
all six A/B/Z signals toward the MCU. U105 supplies both receivers and U101's
field side from PS10 through the shared +3V3_MOTOR_ENC rail. U111, U115 and
their redundant capacitors are removed. Losing PS10 disables feedback from
both motor encoders; PS11 still supplies the Star encoder itself.
Field electronics reference -BATT; MCU outputs reference GND_STM32. J12 and
its optional chassis bond are now on the Port encoder sheet.

| Signal | MCU pin | Nucleo connector | Function |
|---|---|---|---|
| Port A | PA5 | CN7 pin 10 | TIM2_CH1 AF1 |
| Port B | PB3 | CN7 pin 15 | TIM2_CH2 AF1 |
| Port Z | PE4 | CN9 pin 16 | EXTI4 |
| Star A | PC6 | CN7 pin 1 | TIM3_CH1 AF2 |
| Star B | PC7 | CN7 pin 11 | TIM3_CH2 AF2 |
| Star Z | PE3 | CN9 pin 22 | EXTI3 |

Disable SWO on PB3; SWD remains available. Verify the Nucleo PA5 LED input
loading. TIM3 is 16-bit and needs firmware counter-wrap handling. PE6 remains
the existing Star drive fault input.

## Files and validation

Onboard temperature: TH1 measures a board-temperature proxy and TH2 measures
the selected power hot spot. Both are two-pad 1206 NTCs (TDK B57621C5103J062),
on the existing ADS1115 sheet. U21 AIN2/3 read their dividers; U24 already provides
I2C isolation. No additional IC, regulator, isolator, address or bus branch is
needed. Both sensors use +5V_BRAKE/GND_BRAKE; readings require that supply.
The separate temperature sheet and U140/U141/U143/U144 have been removed.

Firmware currently reads only AIN0/1. It must add slow temperature sampling,
use +/-6.144 V for AIN2/3, preserve brake-channel gain/cadence, and convert with
TDK curve 1010 plus calibration. Firmware is not changed by this schematic work.

Open Elevation_Pivot_Daughter-Board.kicad_pro in KiCad 9. Read
[SCHEMATIC_REDESIGN_P3.md](docs/SCHEMATIC_REDESIGN_P3.md) for circuits, the proposed
connector pinout, and remaining checks. The local review export is
outputs/Pivot_Schematic_Review.pdf.

Run `python tools/validate_pivot_schematic.py`. It checks retained connectivity,
explicit channel renaming, original component values/footprints, encoder
interfaces, removed P1 circuits, inherited ERC exclusions, and the PCB hash.
Reports are in outputs/. Baseline data is tied to commit e0909c8.

Current verification results are generated in outputs/pivot_validation.json.
The checker preserves 304 baseline net groups; the twelve new encoder pins and
two formerly NC ADC inputs have separate explicit checks. It also checks header
label style, original component values/footprints, and the unchanged PCB hash.
The two inherited ERC exclusions are unchanged. P3 source before cleanup is
recoverable under _work/before_p3/.

P1 source before cleanup is recoverable under _work/before_p2_cleanup/.
That folder and generated outputs are ignored by Git. The historical P1 report
is superseded and must not be treated as active requirements.

## Remaining work

Confirm actual encoder identity and harness, maximum signal frequency, cable
impedance/bias margin, supply demand/overload behavior, chassis bonding, and
minimum electronics temperature. P3 is not qualified for the possible -50 C
flight environment. Layout, PCB parity/DRC, thermal work, and bench testing
remain future work.

The original project at
C:/Users/Mauro/Documents/KiCad/Elevation_Control_STM32_Daughter-Board remains
the as-built hardware, firmware, UI, and test-history reference.
Repository: https://github.com/mauro-starspec/Elevation_Pivot_Daughter-Board.
The unchanged baseline PCB has three known Nucleo courtyard overlaps.

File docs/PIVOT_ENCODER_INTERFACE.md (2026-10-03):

# Dual pivot incremental encoder interfaces

## Selected motors and encoders

**P3 status, 2026-10-03:** the user now describes NEMA34 motors. The earlier
HT23/ZAA identification below is a reference, not a confirmed description of
the installed hardware. Both existing SSI channels are retained. The new
circuits assume 5 V differential A/B/Z. The user selected DE9 for J20/J21;
the custom pinout must
be verified against the actual encoder and cable. See
[`SCHEMATIC_REDESIGN_P3.md`](SCHEMATIC_REDESIGN_P3.md) for the current shared
ISO7760F isolation circuit. Both receivers now share PS10/U105 logic power;
the MCU allocation from P2 is unchanged.

- Motors: two Applied Motion Products `HT23-553D-ZAC` units
- Encoder: Renco ZAA type, Applied Motion legacy part `970-1001`, enclosed by
  the ZAC motor cover
- Motor product: [HT23-553D-ZAC](https://www.applied-motion.com/s/product/eolstep-motor-high-torqueht23553dzac/01t5i000000xz33AAA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)
- Encoder drawing: [Applied Motion 970-1001 Rev C](https://applied-motion.s3.amazonaws.com/documents/2D-Drawing/970-1001_RevC_Renco_ZAA_0.pdf)
- Encoder family data: [Renco R35i](https://www.renco.com/fileadmin/user_upload/renco/1319497-21_Drehgeber_RENCO_en.pdf)

The old motor page is marked end-of-life. Preserve the exact motor and encoder
part numbers in the schematic and BOM so a replacement is not assumed to have
the same connector, pinout, resolution, or temperature range.

## Electrical characteristics of the earlier reference assembly

| Property | Requirement |
|---|---|
| Supply | 5 V ±10% |
| Output format | Differential A+/A−, B+/B−, and Z+/Z− line-driver signals |
| Resolution | 2,000 signal periods/revolution |
| STM32 x4 resolution | 8,000 counts/revolution |
| Shaft resolution | 0.045° per decoded count |
| Index | One marker/index pulse per motor revolution |
| Encoder interface | Differential line driver compatible with RS-422 reception |
| Encoder family operating range | −30 °C to +115 °C |
| Applied Motion encoder | ZAA / legacy `970-1001` |
| Applied Motion extension cable | `3004-195-xx` family |

The previous GBA assumptions—4,000 counts/revolution, 60 kHz maximum, 130 mA,
and the 8-pin JST pinout—do not apply to this motor.

## Connector and harness warning

The ZAA encoder uses a 15-position connector system rather than the GBA's
8-position JST connector. Applied Motion identifies `3004-195-xx` as the WAA,
YAA, and ZAA extension-cable family, with a JAE connector at the encoder and a
high-density 15-pin D-sub at the drive end.

The encoder provides these electrical connections:

| Signal | Function |
|---|---|
| A+, A− | Quadrature channel A differential pair |
| B+, B− | Quadrature channel B differential pair |
| Z+, Z− | Index differential pair |
| +5 V | Encoder power |
| GND | Encoder power return |
| Shield/drain | Cable shield, terminated according to the final EMC plan |

Do not release the PCB or harness from an internet pin table alone. Verify the
actual installed encoder connector and the exact `3004-195-xx` cable drawing
from both mating viewpoints before assigning PCB connector pin numbers.

## Required PCB signal chain

```text
Port A+/A− -> differential receiver -> STM32 Port timer channel 1
Port B+/B− -> differential receiver -> STM32 Port timer channel 2
Port Z+/Z− -> differential receiver -> STM32 Port index/interrupt input

Star A+/A− -> differential receiver -> STM32 Star timer channel 1
Star B+/B− -> differential receiver -> STM32 Star timer channel 2
Star Z+/Z− -> differential receiver -> STM32 Star index/interrupt input
```

The external differential pairs must not be connected directly to normal STM32
GPIO inputs. Select six RS-422-compatible differential receiver channels whose
logic outputs are natively safe for the STM32H723's 3.3 V domain.

The completed dual-channel circuit should provide:

- receiver-end termination for all six differential pairs, derived from the
  encoder, receiver, and actual cable requirements;
- ESD/transient protection with sufficiently low capacitance;
- local receiver and encoder-supply decoupling;
- a filtered 5 V encoder supply sized from the verified ZAA supply-current
  requirement for two encoders plus design margin;
- twisted differential pairs and a documented cable-shield connection;
- labeled test points on the six receiver outputs;
- each encoder's A and B outputs on channels 1 and 2 of the same STM32 timer in
  hardware encoder mode;
- two Z signals on timer index-capable pins or interrupt inputs;
- canonical channel names `Port` and `Star`; P2 completes the channel and
  supply-net rename across the schematic. The original firmware and unchanged
  PCB retain their historical naming until those are separately updated.

## Position interpretation

With x4 quadrature decoding:

```text
motor_shaft_degrees = encoder_counts * 360 / 8000
motor_shaft_degrees = encoder_counts * 0.045
pivot_degrees = motor_shaft_degrees / mechanical_ratio
```

The final mechanical ratio and sign convention must be confirmed from the pivot
mechanism. The count direction can be reversed in firmware, but the schematic,
harness, and software must document one consistent convention.

## Reference limitation

This is an incremental encoder. Its accumulated count is lost when controller
power is removed. Z identifies one location per motor revolution, but it does
not necessarily identify a unique pivot angle after a gearbox. The system still
requires a startup reference strategy, such as a physical pivot reference
sensor, an operator-established zero, or another absolute measurement.

## Decisions still required

- Verify the two physical encoder labels and connectors
- Obtain the installed cable drawing; verify whether the older `3004-195-xx`
  reference applies at all to the NEMA34 assemblies
- Encoder supply current for the actual installed units
- Pivot mechanical reduction ratio and maximum motor speed
- Maximum encoder cable length and shield termination policy
- Verify P2 receiver, termination, and protection choices against the actual encoder
- Verify P2 TIM2/TIM3 and index allocation against required frequency and firmware
- Required behavior following power loss or motion while unpowered

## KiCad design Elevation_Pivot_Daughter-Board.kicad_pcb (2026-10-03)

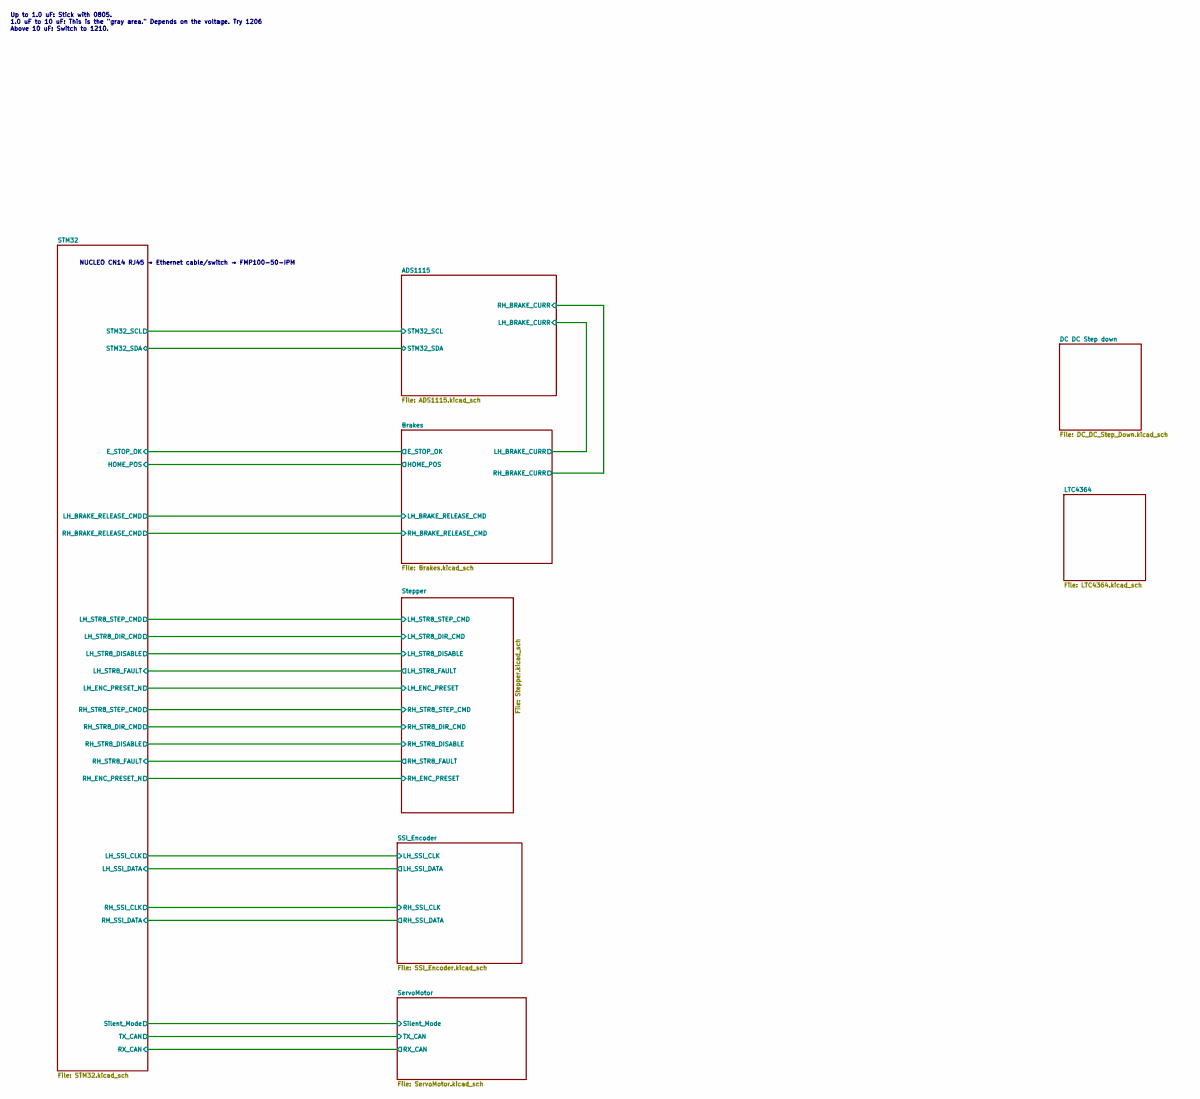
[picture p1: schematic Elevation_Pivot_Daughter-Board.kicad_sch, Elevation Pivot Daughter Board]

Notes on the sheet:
Up to 1.0 uF: Stick with 0805. 1.0 uF to 10 uF: This is the "gray area." Depends on the voltage. Try 1206 Above 10 uF: Switch to 1210.
NUCLEO CN14 RJ45 → Ethernet cable/switch → FMP100-50-IPM

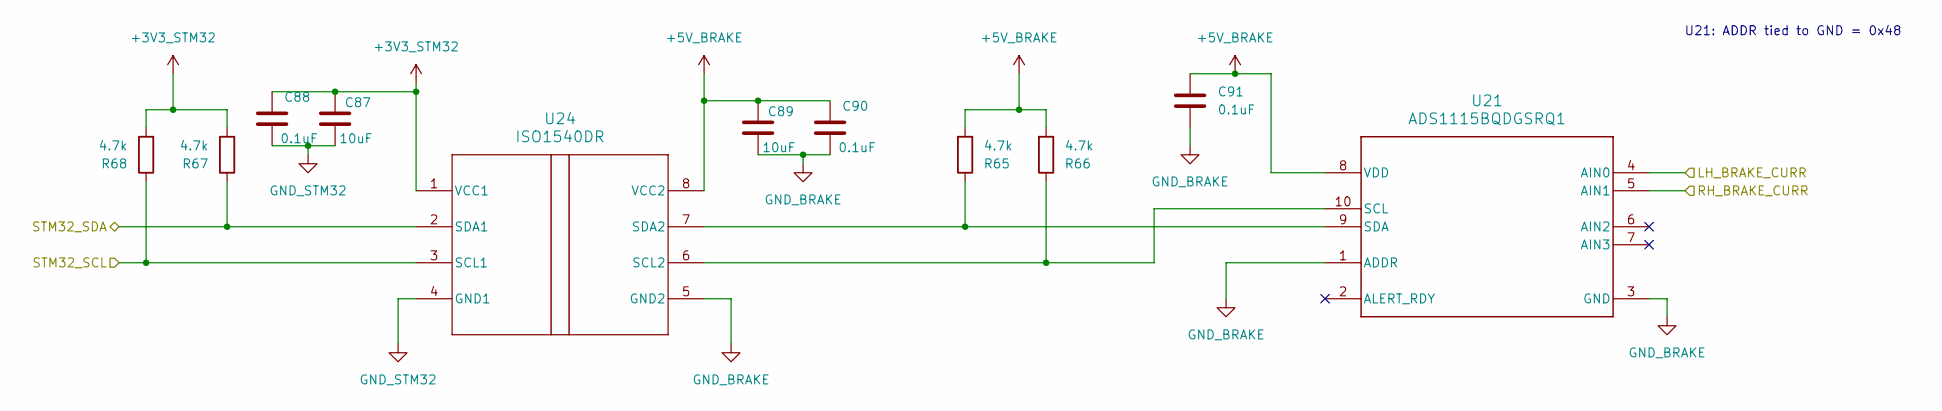
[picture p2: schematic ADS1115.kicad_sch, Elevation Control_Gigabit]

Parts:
C87, C89: 10uF; C_1210_3225Metric; MANUFACTURER_PART_NUMBER CL32B106KBJNFNE; LCSC C18739
C88, C90, C91: 0.1uF; C_0805_2012Metric; MANUFACTURER_PART_NUMBER CL21B104KCFNNNE; LCSC C28233
R65, R66, R67, R68: 4.7k; R_0805_2012Metric; MANUFACTURER_PART_NUMBER RC0805FR-074K7L; LCSC C60816
U21: ADS1115BQDGSRQ1; ADS1115BQDGSRQ1_N; MANUFACTURER_PART_NUMBER ADS1115BQDGSRQ1; LCSC C2868291
U24: ISO1540DR; ISO1540DR_M; MANUFACTURER_PART_NUMBER ISO1540DR; LCSC C179739

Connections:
+3V3_STM32: C87.1, C88.2, R67.2, R68.2, U24.1 (VCC1); also elsewhere on the board
+5V_BRAKE: C89.1, C90.2, C91.1, R65.2, R66.2, U21.8 (VDD), U24.8 (VCC2); also elsewhere on the board
/ADS1115/LH_BRAKE_CURR: U21.4 (AIN0); also elsewhere on the board
/ADS1115/RH_BRAKE_CURR: U21.5 (AIN1); also elsewhere on the board
/ADS1115/STM32_SCL: R68.1, U24.3 (SCL1); also elsewhere on the board
/ADS1115/STM32_SDA: R67.1, U24.2 (SDA1); also elsewhere on the board
GND_BRAKE: C89.2, C90.1, C91.2, U21.1 (ADDR), U21.3 (GND), U24.5 (GND2); also elsewhere on the board
GND_STM32: C87.2, C88.1, U24.4 (GND1); also elsewhere on the board
unnamed: R66.1, U21.10 (SCL), U24.6 (SCL2)
unnamed: R65.1, U21.9 (SDA), U24.7 (SDA2)

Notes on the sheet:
U21: ADDR tied to GND = 0x48

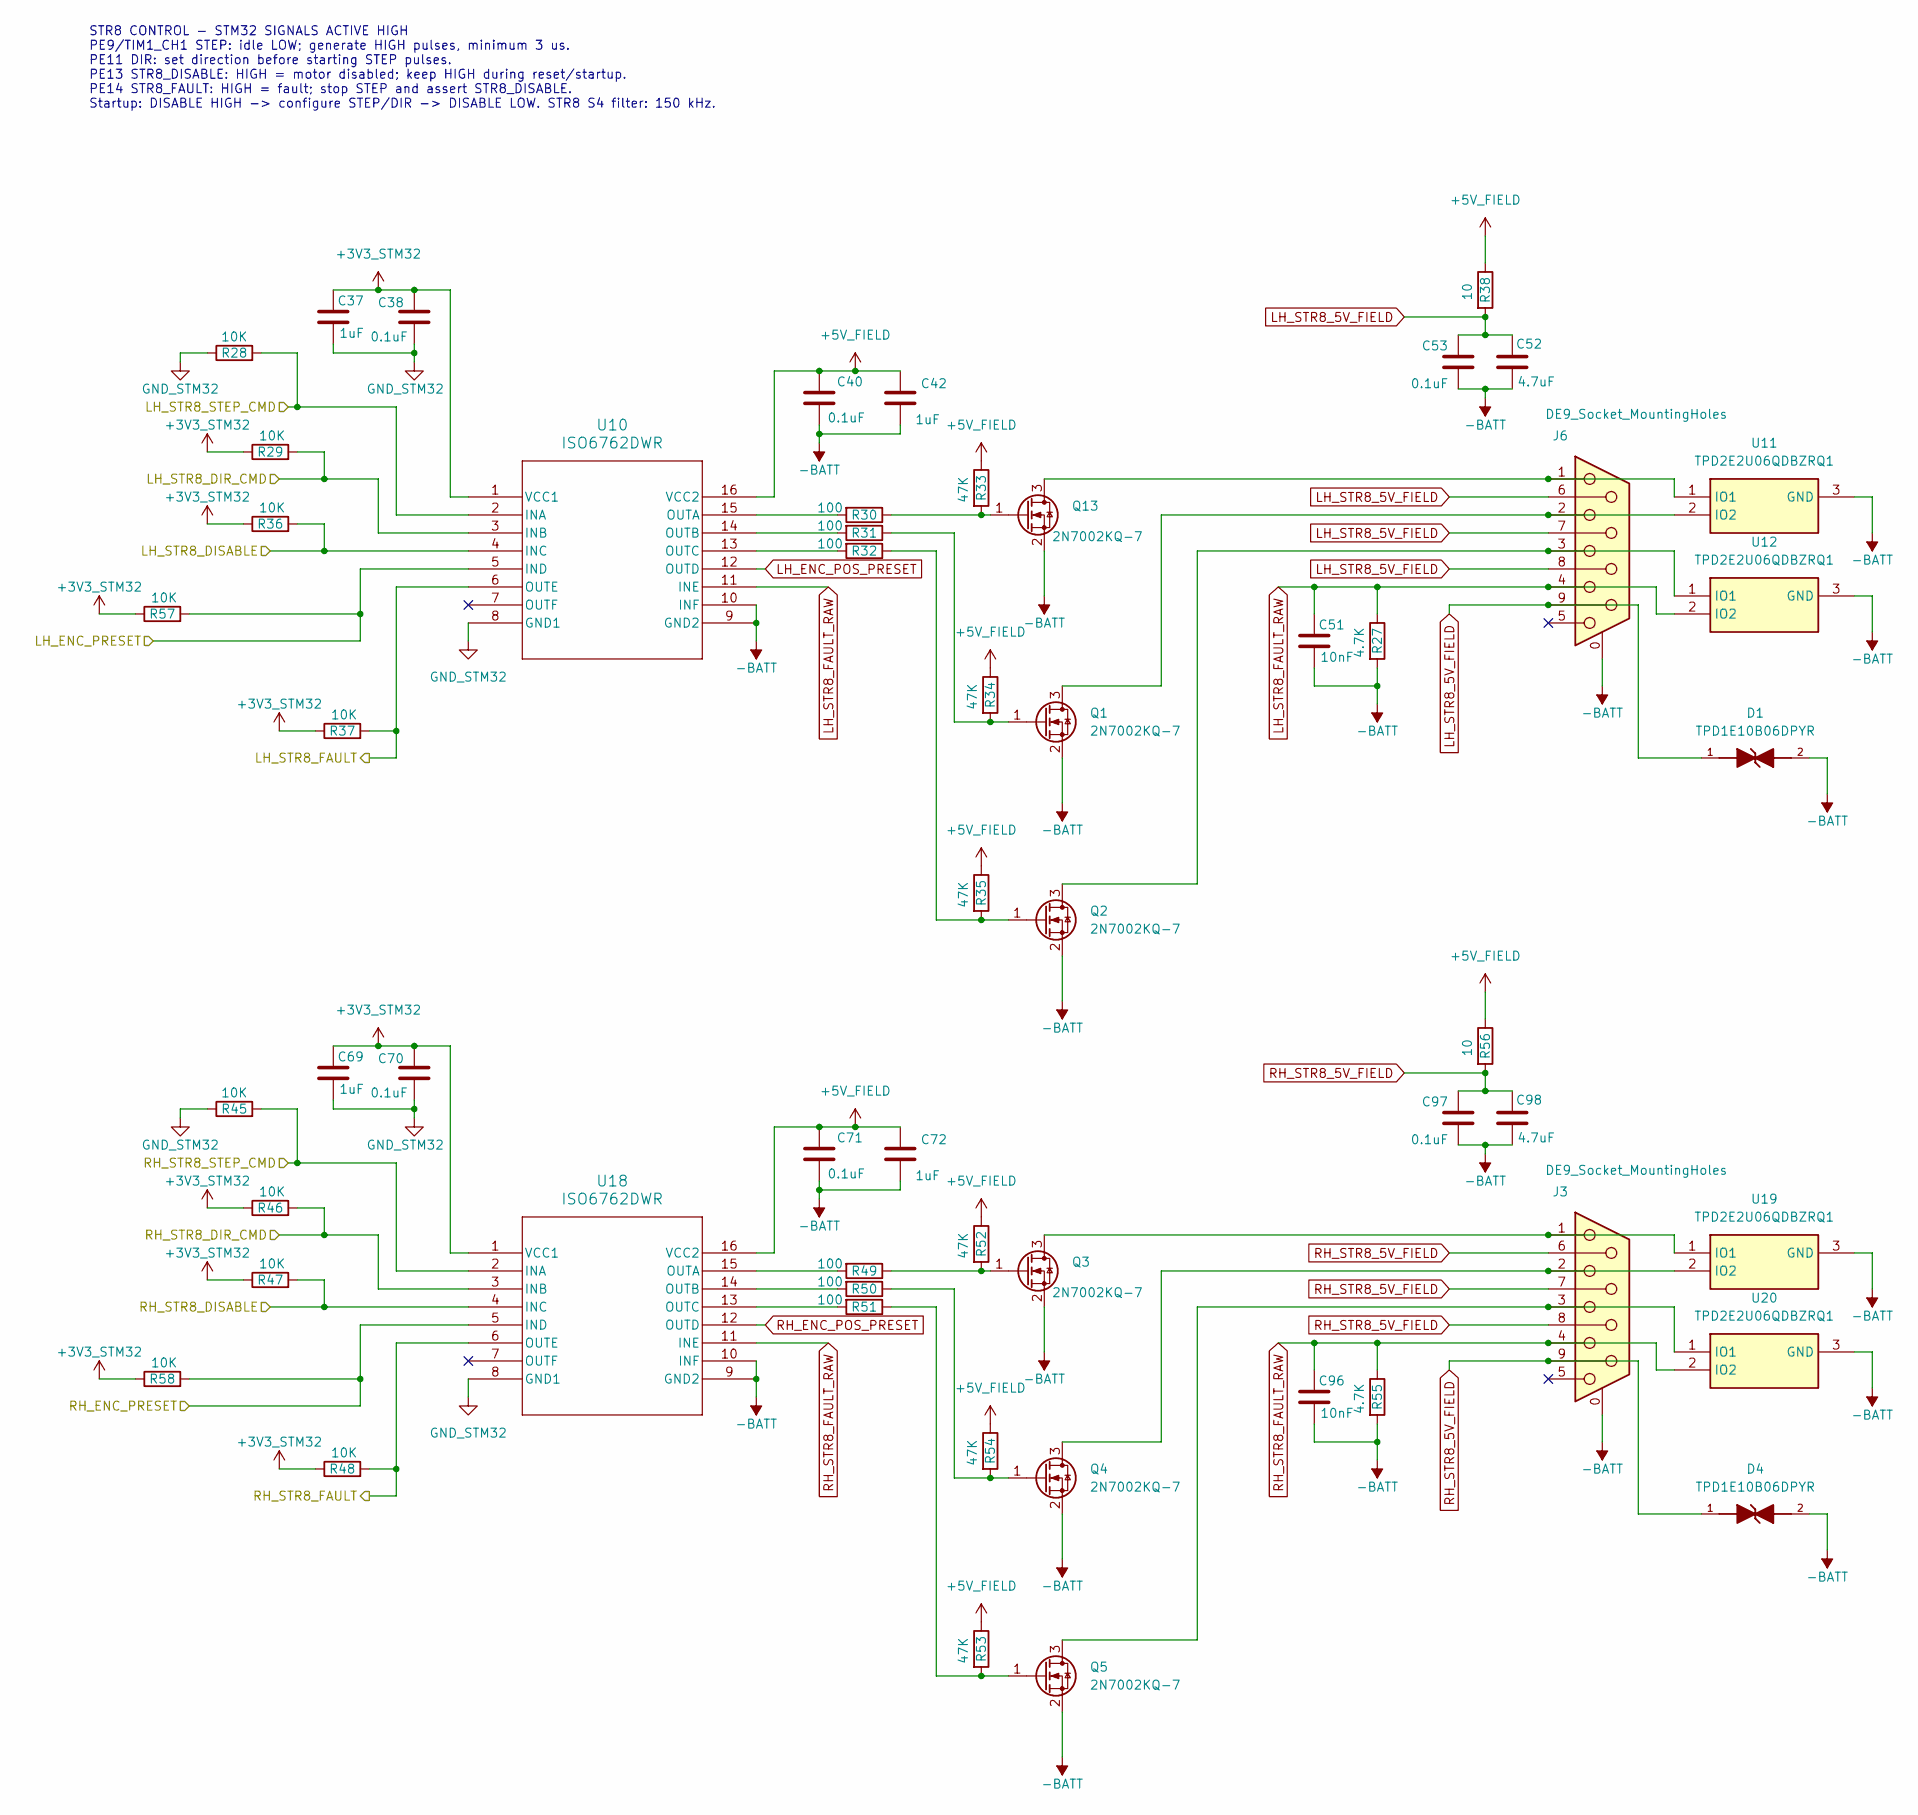
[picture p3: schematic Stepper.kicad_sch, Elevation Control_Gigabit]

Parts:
C37, C42, C69, C72: 1uF; C_1206_3216Metric; MANUFACTURER_PART_NUMBER CL31B105KCHNNNE; LCSC C13832
C38, C40, C53, C70, C71, C97: 0.1uF; C_0805_2012Metric; MANUFACTURER_PART_NUMBER CL21B104KCFNNNE; LCSC C28233
C51, C96: 10nF; C_0805_2012Metric; MANUFACTURER_PART_NUMBER CL21B103KCANNNC; LCSC C18741
C52, C98: 4.7uF; C_1210_3225Metric; MANUFACTURER_PART_NUMBER CL32B475KCVZNWE; LCSC C17288249
D1, D4: TPD1E10B06DPYR; MANUFACTURER_PART_NUMBER TPD1E10B06DPYR; LCSC C48260
J3, J6: DE9_Socket_MountingHoles; DSUB-9_Socket_Horizontal_P2.77x2.84mm_EdgePinOffset7.70mm_H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; MANUFACTURER_PART_NUMBER 5747844-4; LCSC C305941
Q1, Q2, Q3, Q4, Q5, Q13: 2N7002KQ-7; SOT-23; MANUFACTURER_PART_NUMBER 2N7002KQ-7; LCSC C111971
R27, R55: 4.7K; R_0805_2012Metric; MANUFACTURER_PART_NUMBER RC0805FR-074K7L; LCSC C60816
R28, R29, R36, R37, R45, R46, R47, R48, R57, R58: 10K; R_0805_2012Metric; MANUFACTURER_PART_NUMBER RC0805FR-0710KL; LCSC C84376
R30, R31, R32, R49, R50, R51: 100; R_0805_2012Metric; MANUFACTURER_PART_NUMBER RC0805FR-07100RL; LCSC C105577
R33, R34, R35, R52, R53, R54: 47K; R_0805_2012Metric; MANUFACTURER_PART_NUMBER RC0805FR-0747KL; LCSC C126351
R38, R56: 10; R_2512_6332Metric_Pad1.40x3.35mm_HandSolder; MANUFACTURER_PART_NUMBER 352210RFT; LCSC C2075790
U10, U18: ISO6762DWR; ISO6762QDWRQ1; MANUFACTURER_PART_NUMBER ISO6762DWR; LCSC C5216395
U11, U12, U19, U20: TPD2E2U06QDBZRQ1; SOT95P237X95-3N; MANUFACTURER_PART_NUMBER TPD2E2U06QDBZRQ1; LCSC C488151

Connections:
+3V3_STM32: C37.1, C38.2, C69.1, C70.2, R29.1, R36.1, R37.1, R46.1, R47.1, R48.1, R57.1, R58.1, U10.1 (VCC1), U18.1 (VCC1); also elsewhere on the board
+5V_FIELD: C40.2, C42.1, C71.2, C72.1, R33.1, R34.1, R35.1, R38.1, R52.1, R53.1, R54.1, R56.1, U10.16 (VCC2), U18.16 (VCC2); also elsewhere on the board
-BATT: C40.1, C42.2, C51.2, C52.1, C53.1, C71.1, C72.2, C96.2, C97.1, C98.1, D1.2, D4.2, J3.0 (PAD), J6.0 (PAD), Q1.2 (S), Q2.2 (S), Q3.2 (S), Q4.2 (S), Q5.2 (S), Q13.2 (S), R27.2, R55.2, U10.9 (GND2), U10.10 (INF), U11.3 (GND), U12.3 (GND), U18.9 (GND2), U18.10 (INF), U19.3 (GND), U20.3 (GND); also elsewhere on the board
/STM32/LH_ENC_PRESET_N: R57.2, U10.5 (IND); also elsewhere on the board
/STM32/LH_STR8_DIR_CMD: R29.2, U10.3 (INB); also elsewhere on the board
/STM32/LH_STR8_DISABLE: R36.2, U10.4 (INC); also elsewhere on the board
/STM32/LH_STR8_FAULT: R37.2, U10.6 (OUTE); also elsewhere on the board
/STM32/LH_STR8_STEP_CMD: R28.2, U10.2 (INA); also elsewhere on the board
/STM32/RH_ENC_PRESET_N: R58.2, U18.5 (IND); also elsewhere on the board
/STM32/RH_STR8_DIR_CMD: R46.2, U18.3 (INB); also elsewhere on the board
/STM32/RH_STR8_DISABLE: R47.2, U18.4 (INC); also elsewhere on the board
/STM32/RH_STR8_FAULT: R48.2, U18.6 (OUTE); also elsewhere on the board
/STM32/RH_STR8_STEP_CMD: R45.2, U18.2 (INA); also elsewhere on the board
GND_STM32: C37.2, C38.1, C69.2, C70.1, R28.1, R45.1, U10.8 (GND1), U18.8 (GND1); also elsewhere on the board
LH_ENC_POS_PRESET: U10.12 (OUTD); also elsewhere on the board
LH_STR8_5V_FIELD: C52.2, C53.2, D1.1, J6.6, J6.7, J6.8, J6.9, R38.2
LH_STR8_FAULT_RAW: C51.1, J6.4, R27.1, U10.11 (INE), U12.2 (IO2)
unnamed: J6.2, Q1.3 (D), U11.2 (IO2)
unnamed: Q1.1 (G), R31.1, R34.2
unnamed: J6.3, Q2.3 (D), U12.1 (IO1)
unnamed: Q2.1 (G), R32.1, R35.2
unnamed: J3.1, Q3.3 (D), U19.1 (IO1)
unnamed: Q3.1 (G), R49.1, R52.2
unnamed: J3.2, Q4.3 (D), U19.2 (IO2)
unnamed: Q4.1 (G), R50.1, R54.2
unnamed: J3.3, Q5.3 (D), U20.1 (IO1)
unnamed: Q5.1 (G), R51.1, R53.2
unnamed: J6.1, Q13.3 (D), U11.1 (IO1)
unnamed: Q13.1 (G), R30.1, R33.2
unnamed: R30.2, U10.15 (OUTA)
unnamed: R31.2, U10.14 (OUTB)
unnamed: R32.2, U10.13 (OUTC)
unnamed: R49.2, U18.15 (OUTA)
unnamed: R50.2, U18.14 (OUTB)
unnamed: R51.2, U18.13 (OUTC)
RH_ENC_POS_PRESET: U18.12 (OUTD); also elsewhere on the board
RH_STR8_5V_FIELD: C97.2, C98.2, D4.1, J3.6, J3.7, J3.8, J3.9, R56.2
RH_STR8_FAULT_RAW: C96.1, J3.4, R55.1, U18.11 (INE), U20.2 (IO2)

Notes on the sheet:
STR8 CONTROL - STM32 SIGNALS ACTIVE HIGH PE9/TIM1_CH1 STEP: idle LOW; generate HIGH pulses, minimum 3 us. PE11 DIR: set direction before starting STEP pulses. PE13 STR8_DISABLE: HIGH = motor disabled; keep HIGH during reset/startup. PE14 STR8_FAULT: HIGH = fault; stop STEP and assert STR8_DISABLE. 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

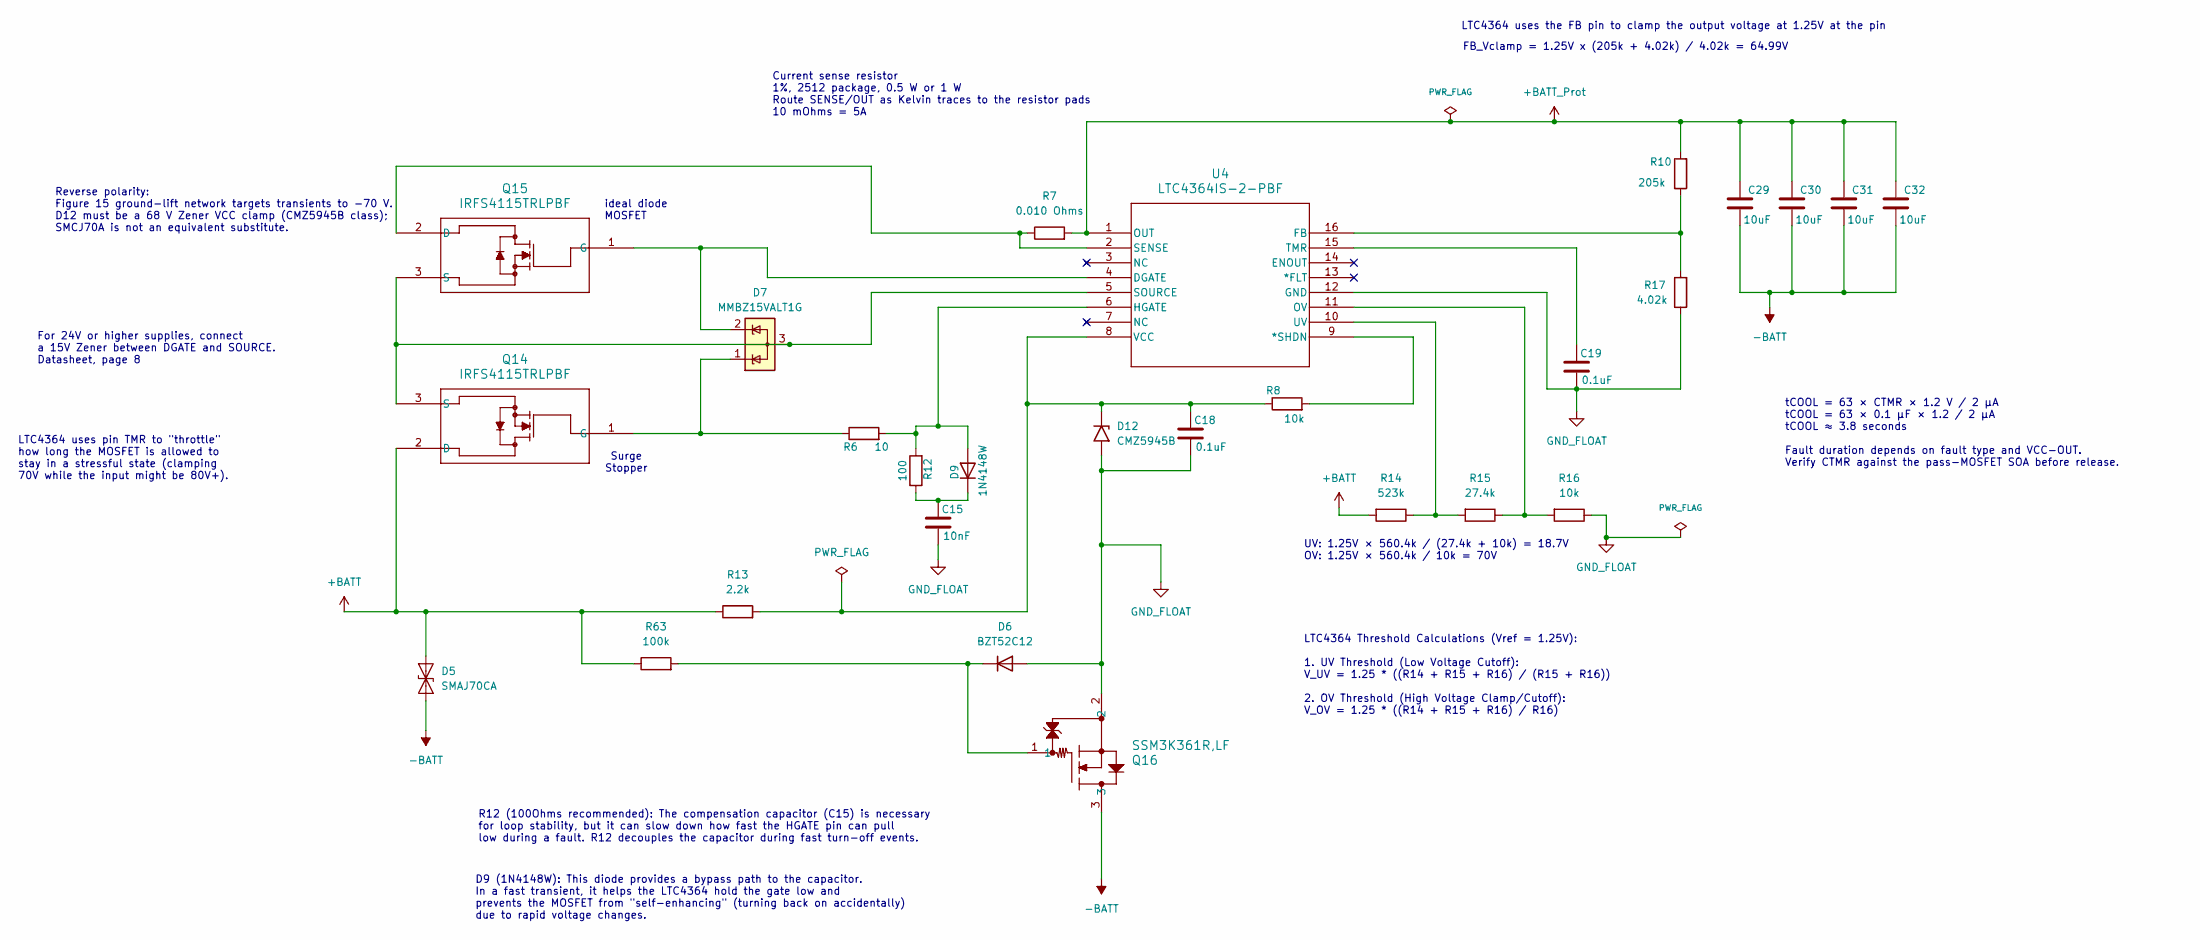
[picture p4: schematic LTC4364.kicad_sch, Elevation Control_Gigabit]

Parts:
C15: 10nF; C_0805_2012Metric; MANUFACTURER_PART_NUMBER CL21B103KCANNNC; LCSC C18741
C18: 0.1uF; C_0805_2012Metric; MANUFACTURER_PART_NUMBER CL21B104KCFNNNE; LCSC C28233
C19: 0.1uF; C_1206_3216Metric; MANUFACTURER_PART_NUMBER GCM31C5C1H104FA16L; LCSC C1864297
C29, C30, C31, C32: 10uF; C_2220_5750Metric; MANUFACTURER_PART_NUMBER FS55X106K101EHG; LCSC C153035
D5: SMAJ70CA; DO-214AC_VIS; MANUFACTURER_PART_NUMBER SMAJ70CA-TR; LCSC C132932
D6: BZT52C12; D_SOD-123; MANUFACTURER_PART_NUMBER BZT52C12; LCSC C43491
D7: MMBZ15VALT1G; SOT-23-3; MANUFACTURER_PART_NUMBER MMBZ15VALT1G; LCSC C22582
D9: 1N4148W; D_SOD-123; MANUFACTURER_PART_NUMBER 1N4148W; LCSC C81598
D12: CMZ5945B; D_SMA_Handsoldering; MANUFACTURER_PART_NUMBER CMZ5945B TR13 PBFREE; LCSC C5240502
Q14, Q15: IRFS4115TRLPBF; SUM80090E-GE3; MANUFACTURER_PART_NUMBER IRFS4115TRLPBF; LCSC C53417
Q16: SSM3K361R,LF; SSM3K361R_LXHF; MANUFACTURER_PART_NUMBER SSM3K361R,LF; LCSC C2762698
R6: 10; R_0805_2012Metric; MANUFACTURER_PART_NUMBER RC0805FR-0710RL; LCSC C96347
R7: 0.010 Ohms; R_2512_6332Metric; MANUFACTURER_PART_NUMBER WSL2512R0100FEA18; LCSC C844902
R8, R16: 10k; R_0805_2012Metric; MANUFACTURER_PART_NUMBER RC0805FR-0710KL; LCSC C84376
R10: 205k; R_0805_2012Metric; MANUFACTURER_PART_NUMBER RT0805BRD07205KL; LCSC C865289
R12: 100; R_0805_2012Metric; MANUFACTURER_PART_NUMBER RC0805FR-07100RL; LCSC C105577
R13: 2.2k; R_0805_2012Metric; MANUFACTURER_PART_NUMBER RC0805FR-072K2L; LCSC C114561
R14: 523k; R_0805_2012Metric; MANUFACTURER_PART_NUMBER RT0805BRD07523KL; LCSC C865545
R15: 27.4k; R_0805_2012Metric; MANUFACTURER_PART_NUMBER RT0805BRD0727K4L; LCSC C865348
R17: 4.02k; R_0805_2012Metric; MANUFACTURER_PART_NUMBER PTFR0805Q4K02P9; LCSC C19687933
R63: 100k; R_0805_2012Metric; MANUFACTURER_PART_NUMBER RC0805FR-07100KL; LCSC C96346
U4: LTC4364IS-2-PBF; LTC4364IS-2; MANUFACTURER_PART_NUMBER LTC4364IS-2#PBF; LCSC C688309

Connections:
+BATT: D5.2 (A2), Q14.2 (D), R13.1, R14.2, R63.1; also elsewhere on the board
+BATT_Prot: C29.1, C30.1, C31.1, C32.1, R7.2, R10.2, U4.1 (OUT); also elsewhere on the board
-BATT: C29.2, C30.2, C31.2, C32.2, D5.1 (A1), Q16.3; also elsewhere on the board
GND_FLOAT: C15.2, C18.2, C19.2, D6.2 (A), D12.2 (A2), Q16.2, R16.1, R17.1, U4.12 (GND)
unnamed: D6.1 (K), Q16.1, R63.2
unnamed: D7.3 (A), Q14.3 (S), Q15.3 (S), U4.5 (SOURCE)
unnamed: D9.2 (A), R6.2, R12.2, U4.6 (HGATE)
unnamed: C15.1, D9.1 (K), R12.1
unnamed: C18.1, D12.1 (A1), R8.1, R13.2, U4.8 (VCC)
unnamed: D7.1 (K), Q14.1 (G), R6.1
unnamed: Q15.2 (D), R7.1, U4.2 (SENSE)
unnamed: D7.2 (K), Q15.1 (G), U4.4 (DGATE)
unnamed: R8.2, U4.9 (*SHDN)
unnamed: R10.1, R17.2, U4.16 (FB)
unnamed: R15.1, R16.2, U4.11 (OV)
unnamed: C19.1, U4.15 (TMR)
unnamed: R14.1, R15.2, U4.10 (UV)

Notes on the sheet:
Surge Stopper
D9 (1N4148W): This diode provides a bypass path to the capacitor. In a fast transient, it helps the LTC4364 hold the gate low and prevents the MOSFET from "self-enhancing" (turning back on accidentally) due to rapid voltage changes.
FB_Vclamp = 1.25V x (205k + 4.02k) / 4.02k = 64.99V
For 24V or higher supplies, connect a 15V Zener between DGATE and SOURCE. Datasheet, page 8
tCOOL = 63 × CTMR × 1.2 V / 2 µA tCOOL = 63 × 0.1 µF × 1.2 / 2 µA tCOOL ≈ 3.8 seconds Fault duration depends on fault type and VCC-OUT. Verify CTMR against the pass-MOSFET SOA before release.
LTC4364 Threshold Calculations (Vref = 1.25V): 1. UV Threshold (Low Voltage Cutoff): V_UV = 1.25 * ((R14 + R15 + R16) / (R15 + R16)) 2. OV Threshold (High Voltage Clamp/Cutoff): V_OV = 1.25 * ((R14 + R15 + R16) / R16)
LTC4364 uses the FB pin to clamp the output voltage at 1.25V at the pin
R12 (100Ohms recommended): The compensation capacitor (C15) is necessary for loop stability, but it can slow down how fast the HGATE pin can pull low during a fault. R12 decouples the capacitor during fast turn-off events.
Current sense resistor 1%, 2512 package, 0.5 W or 1 W Route SENSE/OUT as Kelvin traces to the resistor pads 10 mOhms = 5A
UV: 1.25V × 560.4k / (27.4k + 10k) = 18.7V OV: 1.25V × 560.4k / 10k = 70V
Reverse polarity: Figure 15 ground-lift network targets transients to -70 V. D12 must be a 68 V Zener VCC clamp (CMZ5945B class); SMCJ70A is not an equivalent substitute.
LTC4364 uses pin TMR to "throttle" how long the MOSFET is allowed to stay in a stressful state (clamping 70V while the input might be 80V+).
ideal diode MOSFET

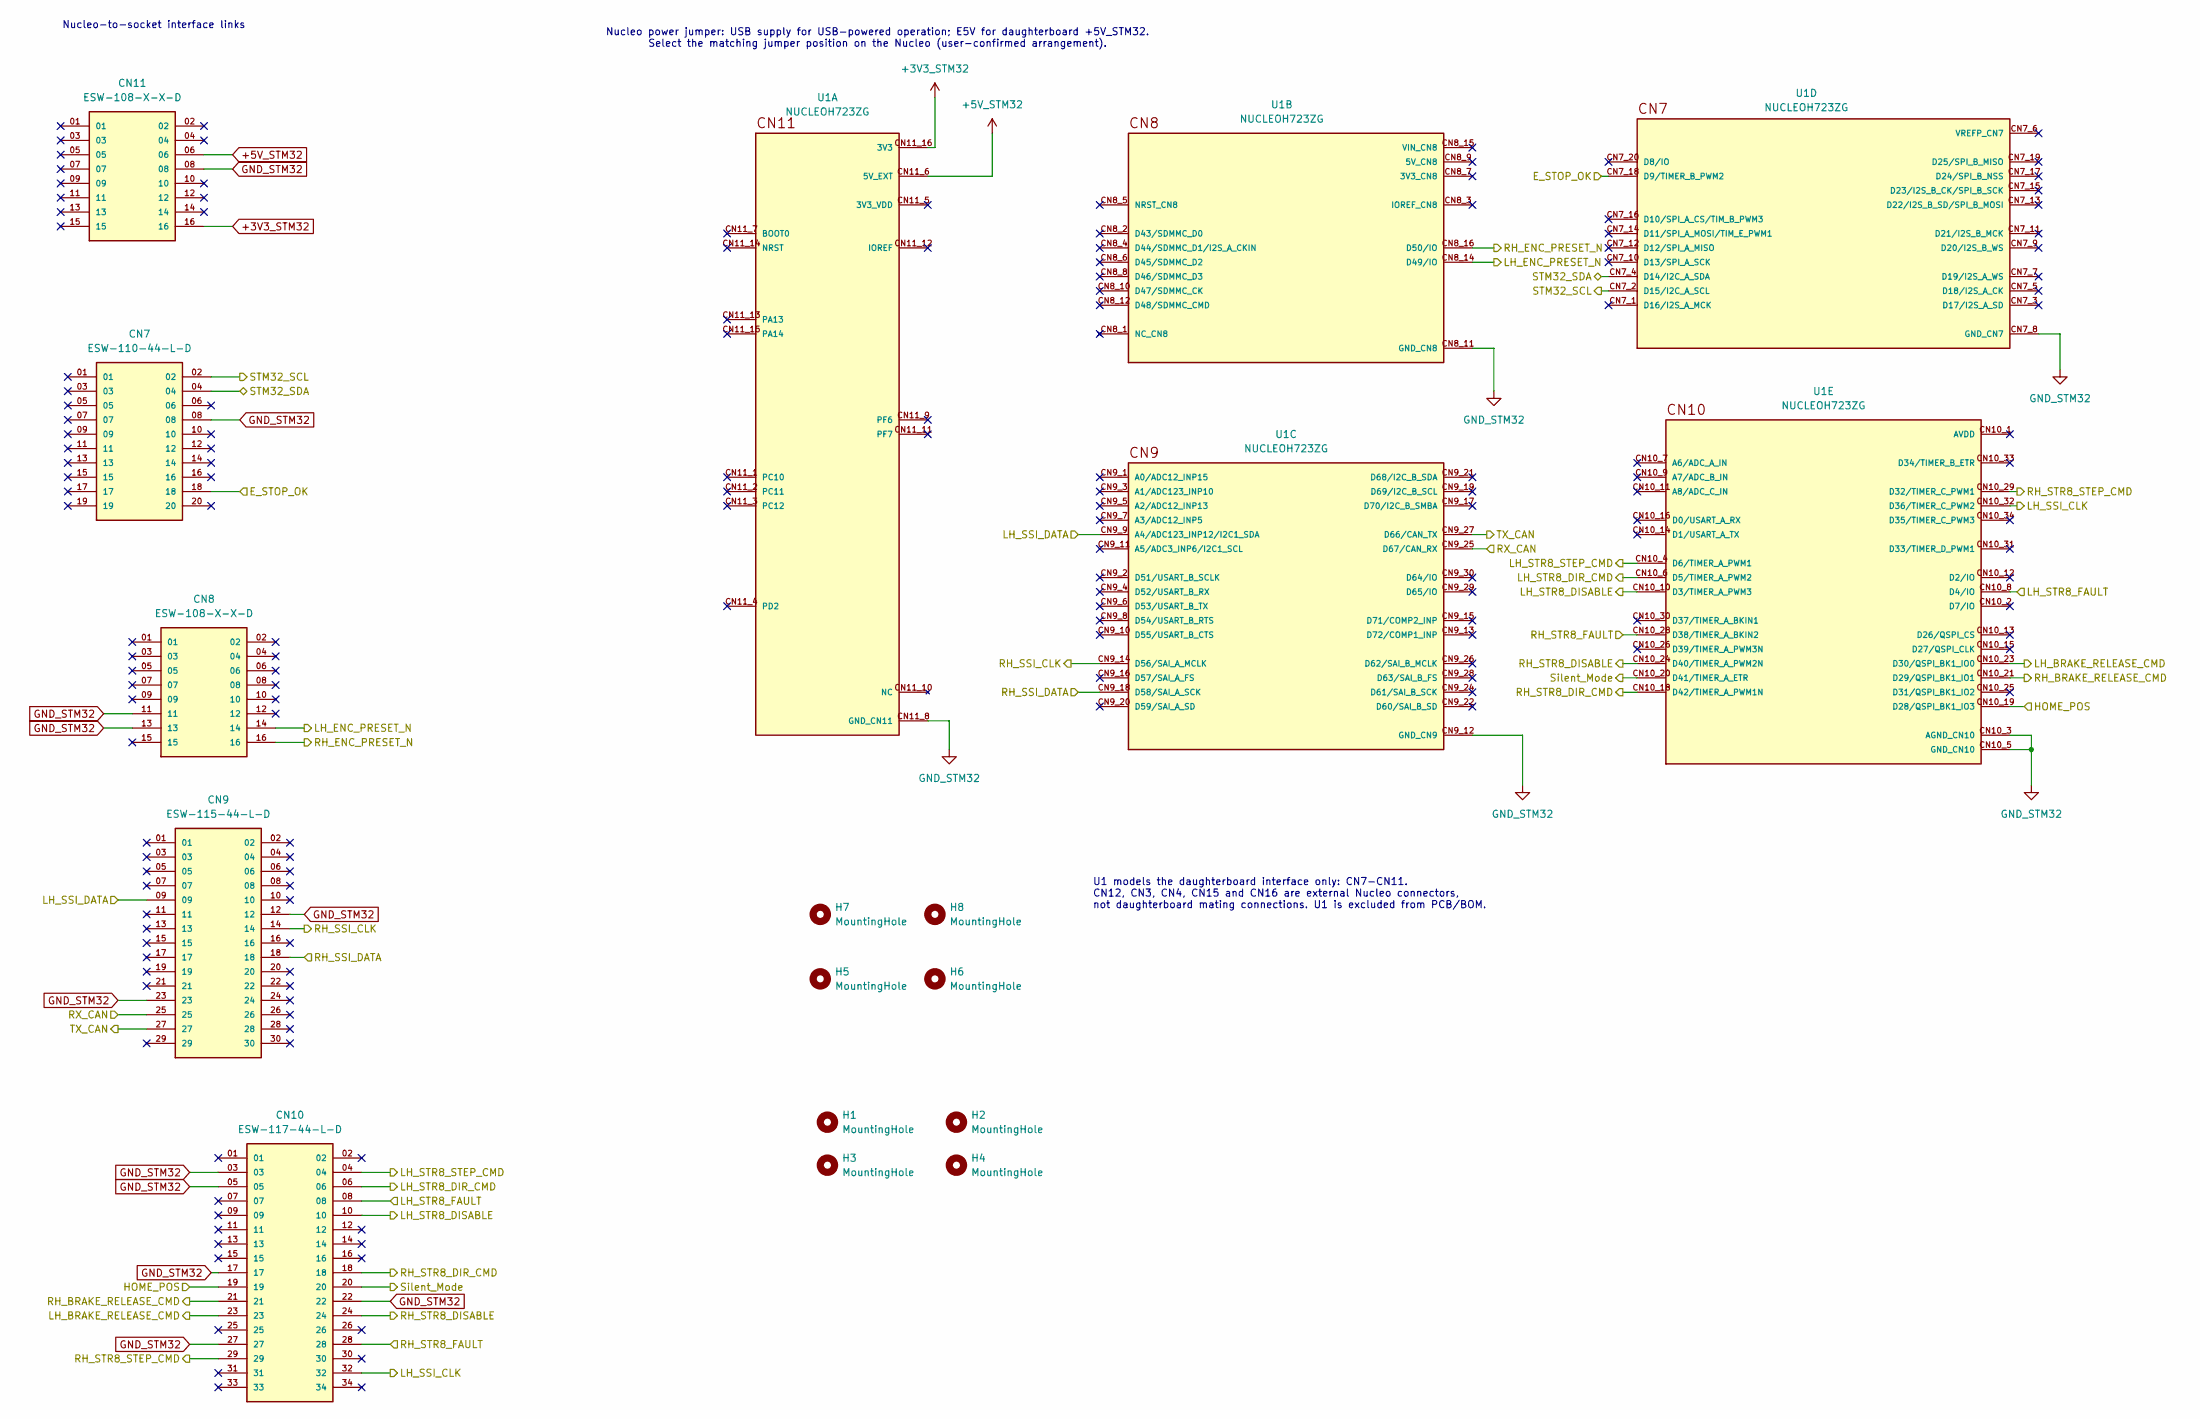
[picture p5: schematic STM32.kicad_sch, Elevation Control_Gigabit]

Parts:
CN7: ESW-110-44-L-D; MANUFACTURER_PART_NUMBER ESW-110-44-L-D
CN8, CN11: ESW-108-X-X-D; ESW-108-44-L-D; MANUFACTURER_PART_NUMBER ESW-108-44-L-D
CN9: ESW-115-44-L-D; MANUFACTURER_PART_NUMBER ESW-115-44-L-D
CN10: ESW-117-44-L-D; MANUFACTURER_PART_NUMBER ESW-117-44-L-D
H1, H2, H3, H4: MountingHole; MountingHole_3.5mm; MANUFACTURER_PART_NUMBER N/A
H5, H6, H7, H8: MountingHole; MountingHole_3.5mm_Pad_TopBottom; MANUFACTURER_PART_NUMBER N/A
U1: NUCLEOH723ZG; MODULE_NUCLEOH723ZG; PARTREV 2

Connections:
+3V3_STM32: CN11.16; also elsewhere on the board
+5V_STM32: CN11.06; also elsewhere on the board
/ADS1115/STM32_SCL: CN7.02, U1.CN7_2 (D15/I2C_A_SCL); also elsewhere on the board
/ADS1115/STM32_SDA: CN7.04, U1.CN7_4 (D14/I2C_A_SDA); also elsewhere on the board
/Brakes/E_STOP_OK: CN7.18, U1.CN7_18 (D9/TIMER_B_PWM2); also elsewhere on the board
/Brakes/HOME_POS: CN10.19, U1.CN10_19 (D28/QSPI_BK1_IO3); also elsewhere on the board
/Brakes/LH_BRAKE_RELEASE_CMD: CN10.23, U1.CN10_23 (D30/QSPI_BK1_IO0); also elsewhere on the board
/Brakes/RH_BRAKE_RELEASE_CMD: CN10.21, U1.CN10_21 (D29/QSPI_BK1_IO1); also elsewhere on the board
/SSI_Encoder/LH_SSI_CLK: CN10.32, U1.CN10_32 (D36/TIMER_C_PWM2); also elsewhere on the board
/SSI_Encoder/LH_SSI_DATA: CN9.09, U1.CN9_9 (A4/ADC123_INP12/I2C1_SDA); also elsewhere on the board
/SSI_Encoder/RH_SSI_CLK: CN9.14, U1.CN9_14 (D56/SAI_A_MCLK); also elsewhere on the board
/SSI_Encoder/RH_SSI_DATA: CN9.18, U1.CN9_18 (D58/SAI_A_SCK); also elsewhere on the board
/STM32/LH_ENC_PRESET_N: CN8.14, U1.CN8_14 (D49/IO); also elsewhere on the board
/STM32/LH_STR8_DIR_CMD: CN10.06, U1.CN10_6 (D5/TIMER_A_PWM2); also elsewhere on the board
/STM32/LH_STR8_DISABLE: CN10.10, U1.CN10_10 (D3/TIMER_A_PWM3); also elsewhere on the board
/STM32/LH_STR8_FAULT: CN10.08, U1.CN10_8 (D4/IO); also elsewhere on the board
/STM32/LH_STR8_STEP_CMD: CN10.04, U1.CN10_4 (D6/TIMER_A_PWM1); also elsewhere on the board
/STM32/RH_ENC_PRESET_N: CN8.16, U1.CN8_16 (D50/IO); also elsewhere on the board
/STM32/RH_STR8_DIR_CMD: CN10.18, U1.CN10_18 (D42/TIMER_A_PWM1N); also elsewhere on the board
/STM32/RH_STR8_DISABLE: CN10.24, U1.CN10_24 (D40/TIMER_A_PWM2N); also elsewhere on the board
/STM32/RH_STR8_FAULT: CN10.28, U1.CN10_28 (D38/TIMER_A_BKIN2); also elsewhere on the board
/STM32/RH_STR8_STEP_CMD: CN10.29, U1.CN10_29 (D32/TIMER_C_PWM1); also elsewhere on the board
/STM32/RX_CAN: CN9.25, U1.CN9_25 (D67/CAN_RX); also elsewhere on the board
/STM32/Silent_Mode: CN10.20, U1.CN10_20 (D41/TIMER_A_ETR); also elsewhere on the board
/STM32/TX_CAN: CN9.27, U1.CN9_27 (D66/CAN_TX); also elsewhere on the board
GND_STM32: CN7.08, CN8.11, CN8.13, CN9.12, CN9.23, CN10.03, CN10.05, CN10.17, CN10.22, CN10.27, CN11.08; also elsewhere on the board
unnamed: U1.CN7_8 (GND_CN7), U1.CN8_11 (GND_CN8), U1.CN8_13 (GND_CN8), U1.CN9_12 (GND_CN9), U1.CN9_23 (GND_CN9), U1.CN10_3 (AGND_CN10), U1.CN10_5 (GND_CN10), U1.CN10_17 (GND_CN10), U1.CN10_22 (GND_CN10), U1.CN10_27 (GND_CN10), U1.CN11_8 (GND_CN11)

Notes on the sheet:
Nucleo power jumper: USB supply for USB-powered operation; E5V for daughterboard +5V_STM32. Select the matching jumper position on the Nucleo (user-confirmed arrangement).
U1 models the daughterboard interface only: CN7-CN11. CN12, CN3, CN4, CN15 and CN16 are external Nucleo connectors, not daughterboard mating connections. U1 is excluded from PCB/BOM.
Nucleo-to-socket interface links

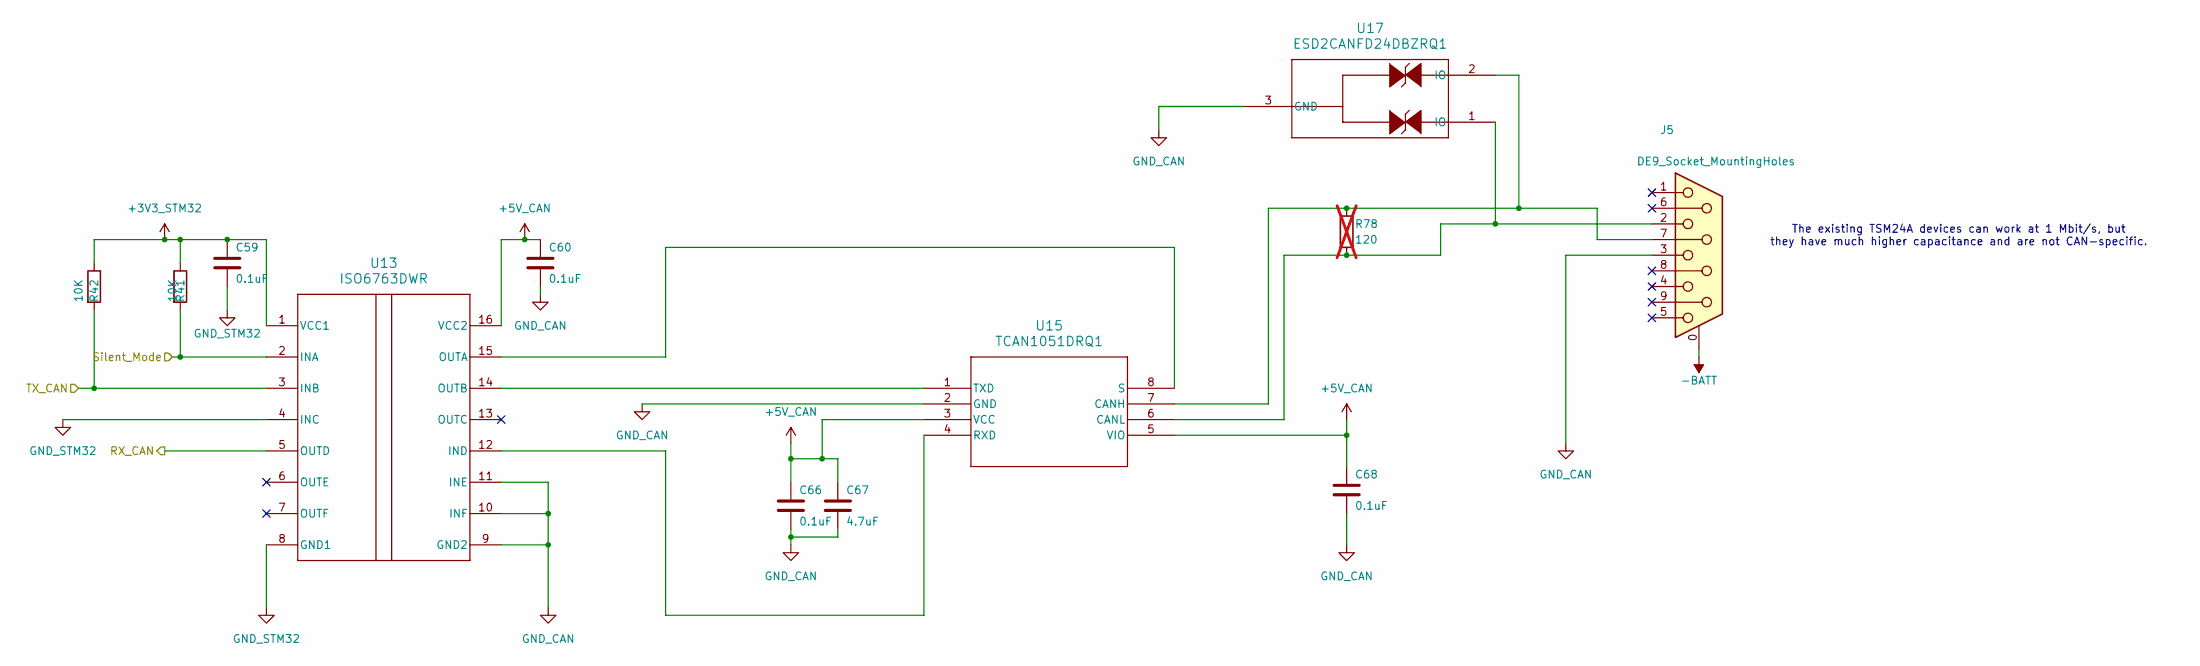
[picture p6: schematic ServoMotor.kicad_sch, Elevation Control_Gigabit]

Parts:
C59, C60, C66, C68: 0.1uF; C_0805_2012Metric; MANUFACTURER_PART_NUMBER CL21B104KCFNNNE; LCSC C28233
C67: 4.7uF; C_1210_3225Metric; MANUFACTURER_PART_NUMBER CL32B475KCVZNWE; LCSC C17288249
J5: DE9_Socket_MountingHoles; DSUB-9_Socket_Horizontal_P2.77x2.84mm_EdgePinOffset7.70mm_H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; MANUFACTURER_PART_NUMBER 5747844-4; LCSC C305941
R41, R42: 10K; R_0805_2012Metric; MANUFACTURER_PART_NUMBER RC0805FR-0710KL; LCSC C84376
R78: 120; R_0805_2012Metric_Pad1.20x1.40mm_HandSolder; MANUFACTURER_PART_NUMBER RC0805FR-07120RL; LCSC C114245; not fitted
U13: ISO6763DWR; MANUFACTURER_PART_NUMBER ISO6763DWR; LCSC C5216409
U15: TCAN1051DRQ1; TCAN1051HGVDRQ1; MANUFACTURER_PART_NUMBER TCAN1051DRQ1; LCSC C2671229
U17: ESD2CANFD24DBZRQ1; MANUFACTURER_PART_NUMBER ESD2CANFD24DBZRQ1; LCSC C20345392

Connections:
+3V3_STM32: C59.1, R41.1, R42.1, U13.1 (VCC1); also elsewhere on the board
+5V_CAN: C60.1, C66.1, C67.1, C68.1, U13.16 (VCC2), U15.3 (VCC), U15.5 (VIO); also elsewhere on the board
-BATT: J5.0 (PAD); also elsewhere on the board
/STM32/RX_CAN: U13.5 (OUTD); also elsewhere on the board
/STM32/Silent_Mode: R41.2, U13.2 (INA); also elsewhere on the board
/STM32/TX_CAN: R42.2, U13.3 (INB); also elsewhere on the board
GND_CAN: C60.2, C66.2, C67.2, C68.2, J5.3, U13.9 (GND2), U13.10 (INF), U13.11 (INE), U15.2 (GND), U17.3 (GND); also elsewhere on the board
GND_STM32: C59.2, U13.4 (INC), U13.8 (GND1); also elsewhere on the board
unnamed: U13.12 (IND), U15.4 (RXD)
unnamed: U13.15 (OUTA), U15.8 (S)
unnamed: U13.14 (OUTB), U15.1 (TXD)
unnamed: J5.7, R78.1, U15.7 (CANH), U17.2 (IO)
unnamed: J5.2, R78.2, U15.6 (CANL), U17.1 (IO)

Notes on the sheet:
The existing TSM24A devices can work at 1 Mbit/s, but they have much higher capacitance and are not CAN-specific.

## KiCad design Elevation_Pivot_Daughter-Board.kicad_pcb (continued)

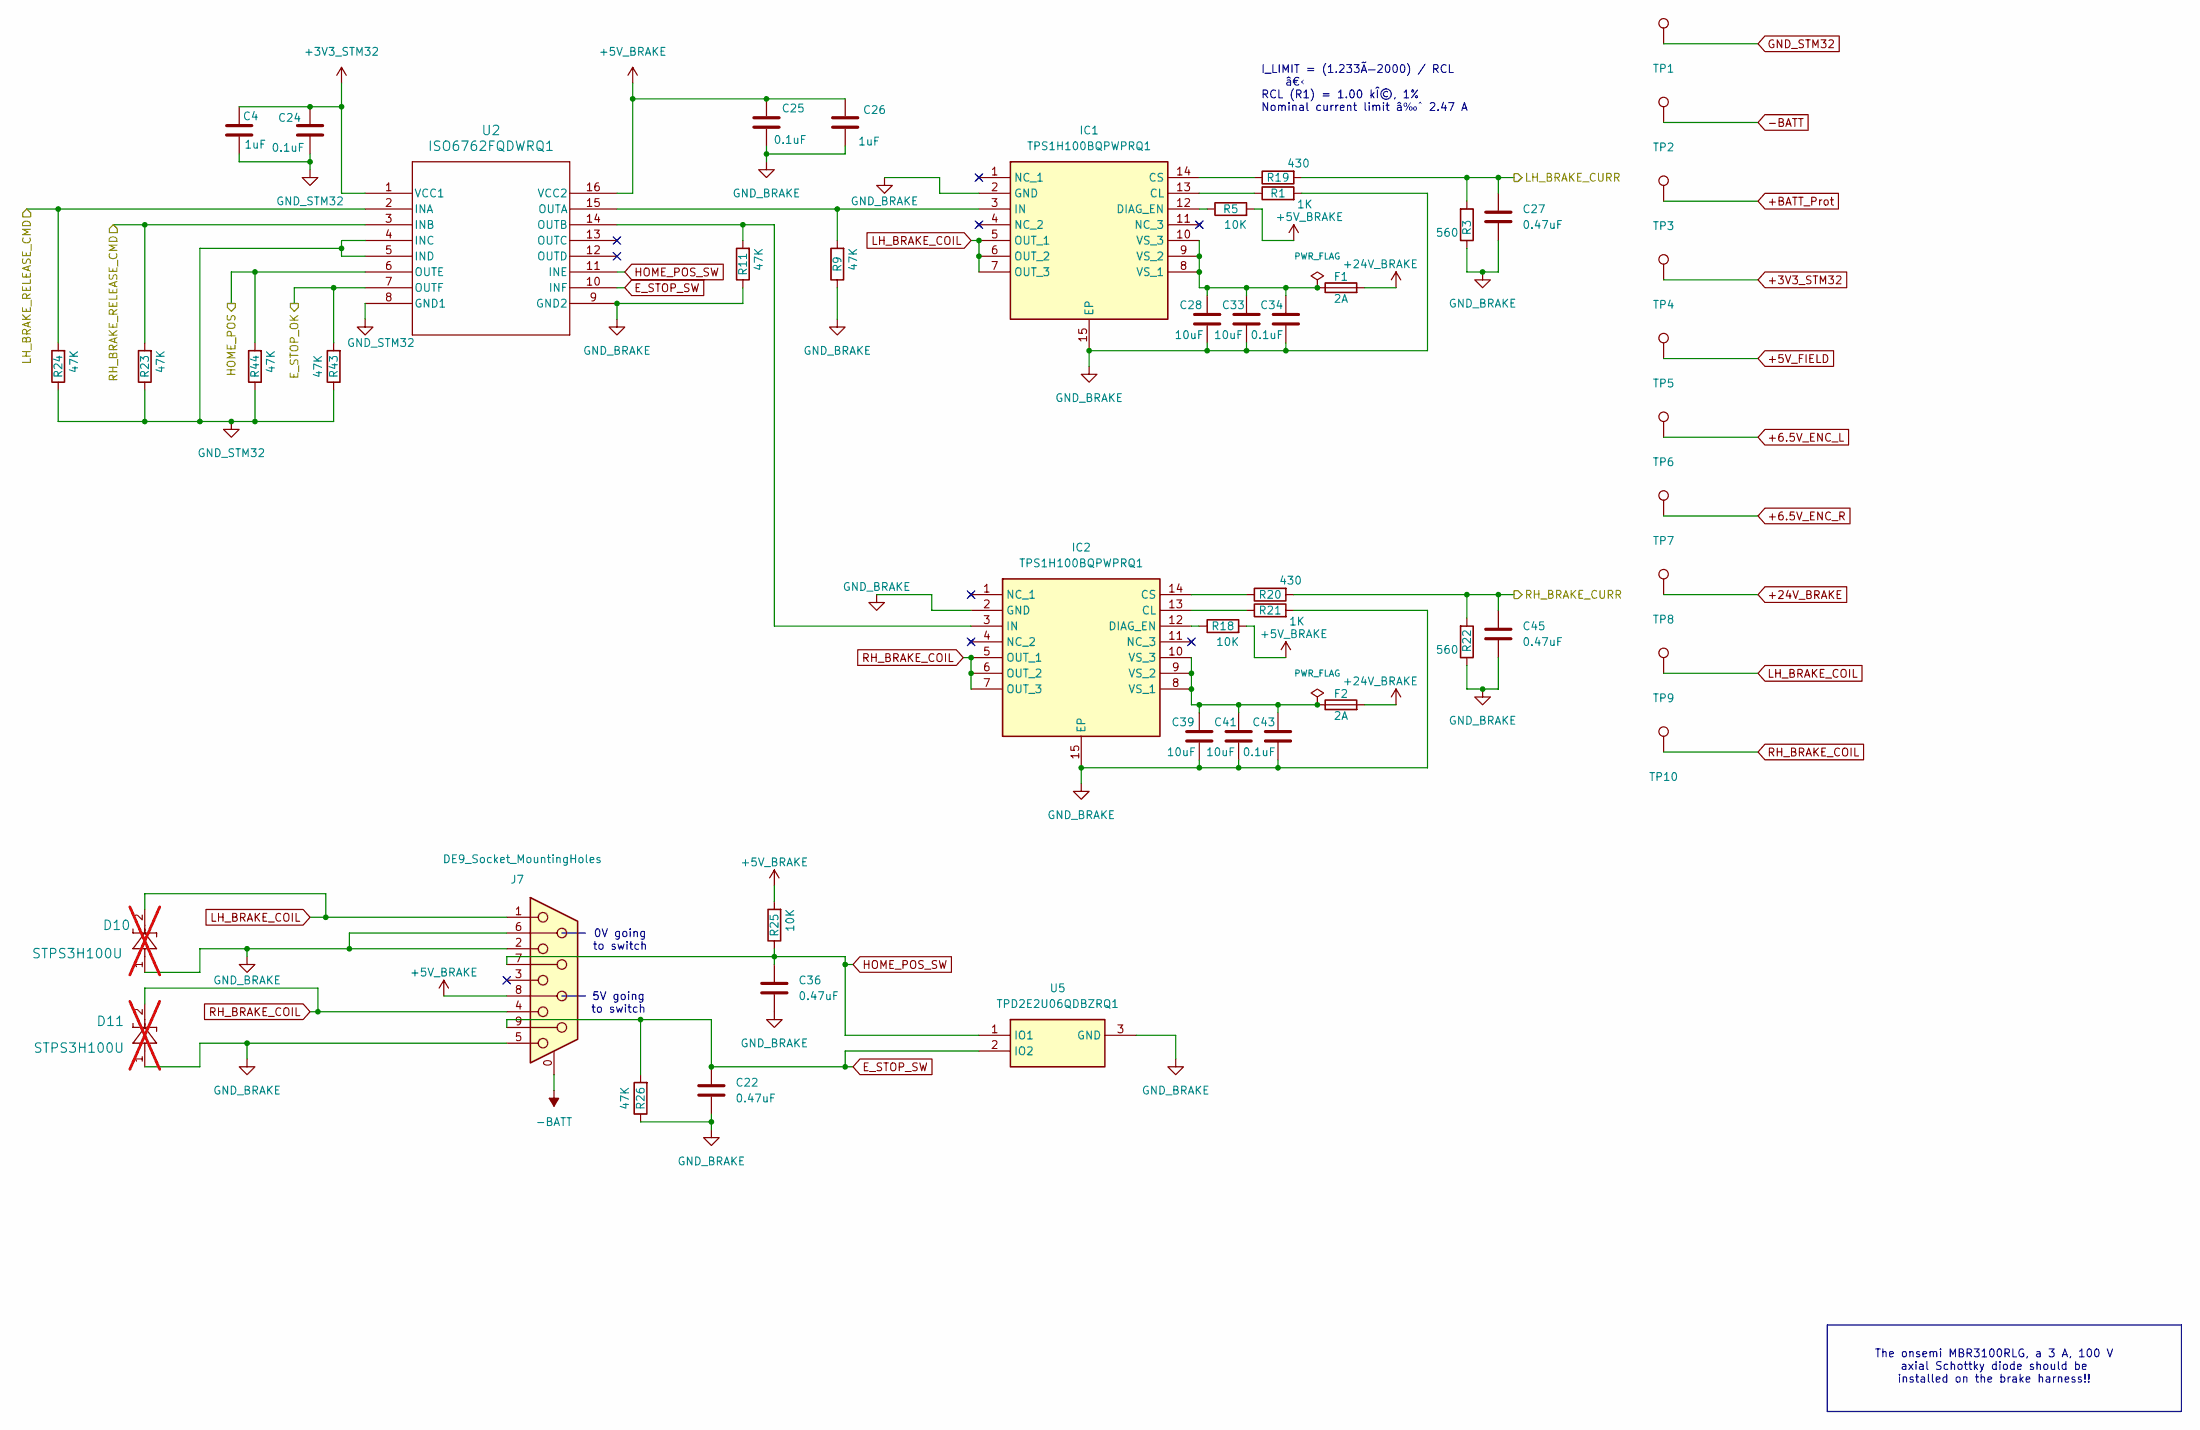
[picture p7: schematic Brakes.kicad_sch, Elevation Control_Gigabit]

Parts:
C4, C26: 1uF; C_1206_3216Metric; MANUFACTURER_PART_NUMBER CL31B105KCHNNNE; LCSC C13832
C22, C27, C36, C45: 0.47uF; C_0805_2012Metric; MANUFACTURER_PART_NUMBER CL21B474KBFNNNE; LCSC C13967
C24, C25, C34, C43: 0.1uF; C_0805_2012Metric; MANUFACTURER_PART_NUMBER CL21B104KCFNNNE; LCSC C28233
C28, C33, C39, C41: 10uF; C_2220_5750Metric; MANUFACTURER_PART_NUMBER FS55X106K101EHG; LCSC C153035
D10, D11: STPS3H100U; MANUFACTURER_PART_NUMBER STPS3H100U; not fitted
F1, F2: 2A; Fuse_1206_3216Metric; MANUFACTURER_PART_NUMBER 0466002.NRHF; LCSC C3105
IC1, IC2: TPS1H100BQPWPRQ1; MANUFACTURER_PART_NUMBER TPS1H100BQPWPRQ1; LCSC C475505
J7: DE9_Socket_MountingHoles; DSUB-9_Socket_Horizontal_P2.77x2.84mm_EdgePinOffset7.70mm_H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; MANUFACTURER_PART_NUMBER 5747844-4; LCSC C305941
R1, R21: 1K; R_0805_2012Metric; MANUFACTURER_PART_NUMBER RC0805FR-071KL; LCSC C95781
R3, R22: 560; R_0805_2012Metric; MANUFACTURER_PART_NUMBER RC0805FR-07560RL; LCSC C114536
R5, R18, R25: 10K; R_0805_2012Metric; MANUFACTURER_PART_NUMBER RC0805FR-0710KL; LCSC C84376
R9, R11, R23, R24, R26, R43, R44: 47K; R_0805_2012Metric; MANUFACTURER_PART_NUMBER RC0805FR-0747KL; LCSC C126351
R19, R20: 430; R_0805_2012Metric; MANUFACTURER_PART_NUMBER RC0805FR-07430RL; LCSC C137527
TP1: GND_STM32; TestPoint_Pad_D3.0mm
TP2: -BATT; TestPoint_Pad_D3.0mm
TP3: +BATT_Prot; TestPoint_Pad_D3.0mm
TP4: +3V3_STM32; TestPoint_Pad_D3.0mm
TP5: +5V_FIELD; TestPoint_Pad_D3.0mm
TP6: +6.5V_ENC_L; TestPoint_Pad_D3.0mm
TP7: +6.5V_ENC_R; TestPoint_Pad_D3.0mm
TP8: +24V_BRAKE; TestPoint_Pad_D3.0mm
TP9: LH_BRAKE_COIL; TestPoint_Pad_D3.0mm
TP10: RH_BRAKE_COIL; TestPoint_Pad_D3.0mm
U2: ISO6762FQDWRQ1; MANUFACTURER_PART_NUMBER ISO6762FQDWRQ1; LCSC C5216383
U5: TPD2E2U06QDBZRQ1; SOT95P237X95-3N; MANUFACTURER_PART_NUMBER TPD2E2U06QDBZRQ1; LCSC C488151

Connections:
+3V3_STM32: C4.1, C24.2, TP4.1, U2.1 (VCC1); also elsewhere on the board
+5V_BRAKE: C25.2, C26.1, J7.8, R5.2, R18.2, R25.2, U2.16 (VCC2); also elsewhere on the board
+5V_FIELD: TP5.1; also elsewhere on the board
+6.5V_ENC_L: TP6.1; also elsewhere on the board
+6.5V_ENC_R: TP7.1; also elsewhere on the board
+24V_BRAKE: F1.2, F2.2, TP8.1; also elsewhere on the board
+BATT_Prot: TP3.1; also elsewhere on the board
-BATT: J7.0 (PAD), TP2.1; also elsewhere on the board
/ADS1115/LH_BRAKE_CURR: C27.1, R3.2, R19.2; also elsewhere on the board
/ADS1115/RH_BRAKE_CURR: C45.1, R20.2, R22.2; also elsewhere on the board
/Brakes/E_STOP_OK: R43.2, U2.7 (OUTF); also elsewhere on the board
/Brakes/HOME_POS: R44.2, U2.6 (OUTE); also elsewhere on the board
/Brakes/LH_BRAKE_RELEASE_CMD: R24.2, U2.2 (INA); also elsewhere on the board
/Brakes/RH_BRAKE_RELEASE_CMD: R23.2, U2.3 (INB); also elsewhere on the board
E_STOP_SW: C22.1, J7.9, R26.2, U2.10 (INF), U5.2 (IO2)
GND_BRAKE: C22.2, C25.1, C26.2, C27.2, C28.2, C33.2, C34.1, C36.2, C39.2, C41.2, C43.1, C45.2, D10.1, D11.1, IC1.2 (GND), IC1.15 (EP), IC2.2 (GND), IC2.15 (EP), J7.2, J7.5, J7.6, R1.2, R3.1, R9.1, R11.1, R21.2, R22.1, R26.1, U2.9 (GND2), U5.3 (GND); also elsewhere on the board
GND_STM32: C4.2, C24.1, R23.1, R24.1, R43.1, R44.1, TP1.1, U2.4 (INC), U2.5 (IND), U2.8 (GND1); also elsewhere on the board
HOME_POS_SW: C36.1, J7.7, R25.1, U2.11 (INE), U5.1 (IO1)
LH_BRAKE_COIL: D10.2, IC1.5 (OUT_1), IC1.6 (OUT_2), IC1.7 (OUT_3), J7.1, TP9.1
unnamed: IC1.13 (CL), R1.1
unnamed: IC1.14 (CS), R19.1
unnamed: IC1.12 (DIAG_EN), R5.1
unnamed: IC1.3 (IN), R9.2, U2.15 (OUTA)
unnamed: C28.1, C33.1, C34.2, F1.1, IC1.8 (VS_1), IC1.9 (VS_2), IC1.10 (VS_3)
unnamed: IC2.13 (CL), R21.1
unnamed: IC2.14 (CS), R20.1
unnamed: IC2.12 (DIAG_EN), R18.1
unnamed: IC2.3 (IN), R11.2, U2.14 (OUTB)
unnamed: C39.1, C41.1, C43.2, F2.1, IC2.8 (VS_1), IC2.9 (VS_2), IC2.10 (VS_3)
RH_BRAKE_COIL: D11.2, IC2.5 (OUT_1), IC2.6 (OUT_2), IC2.7 (OUT_3), J7.4, TP10.1

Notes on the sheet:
0V going to switch
The onsemi MBR3100RLG, a 3 A, 100 V axial Schottky diode should be installed on the brake harness!!
5V going to switch
I_LIMIT = (1.233Ã—2000) / RCL â€‹ RCL (R1) = 1.00 kÎ©, 1% Nominal current limit â‰ˆ 2.47 A

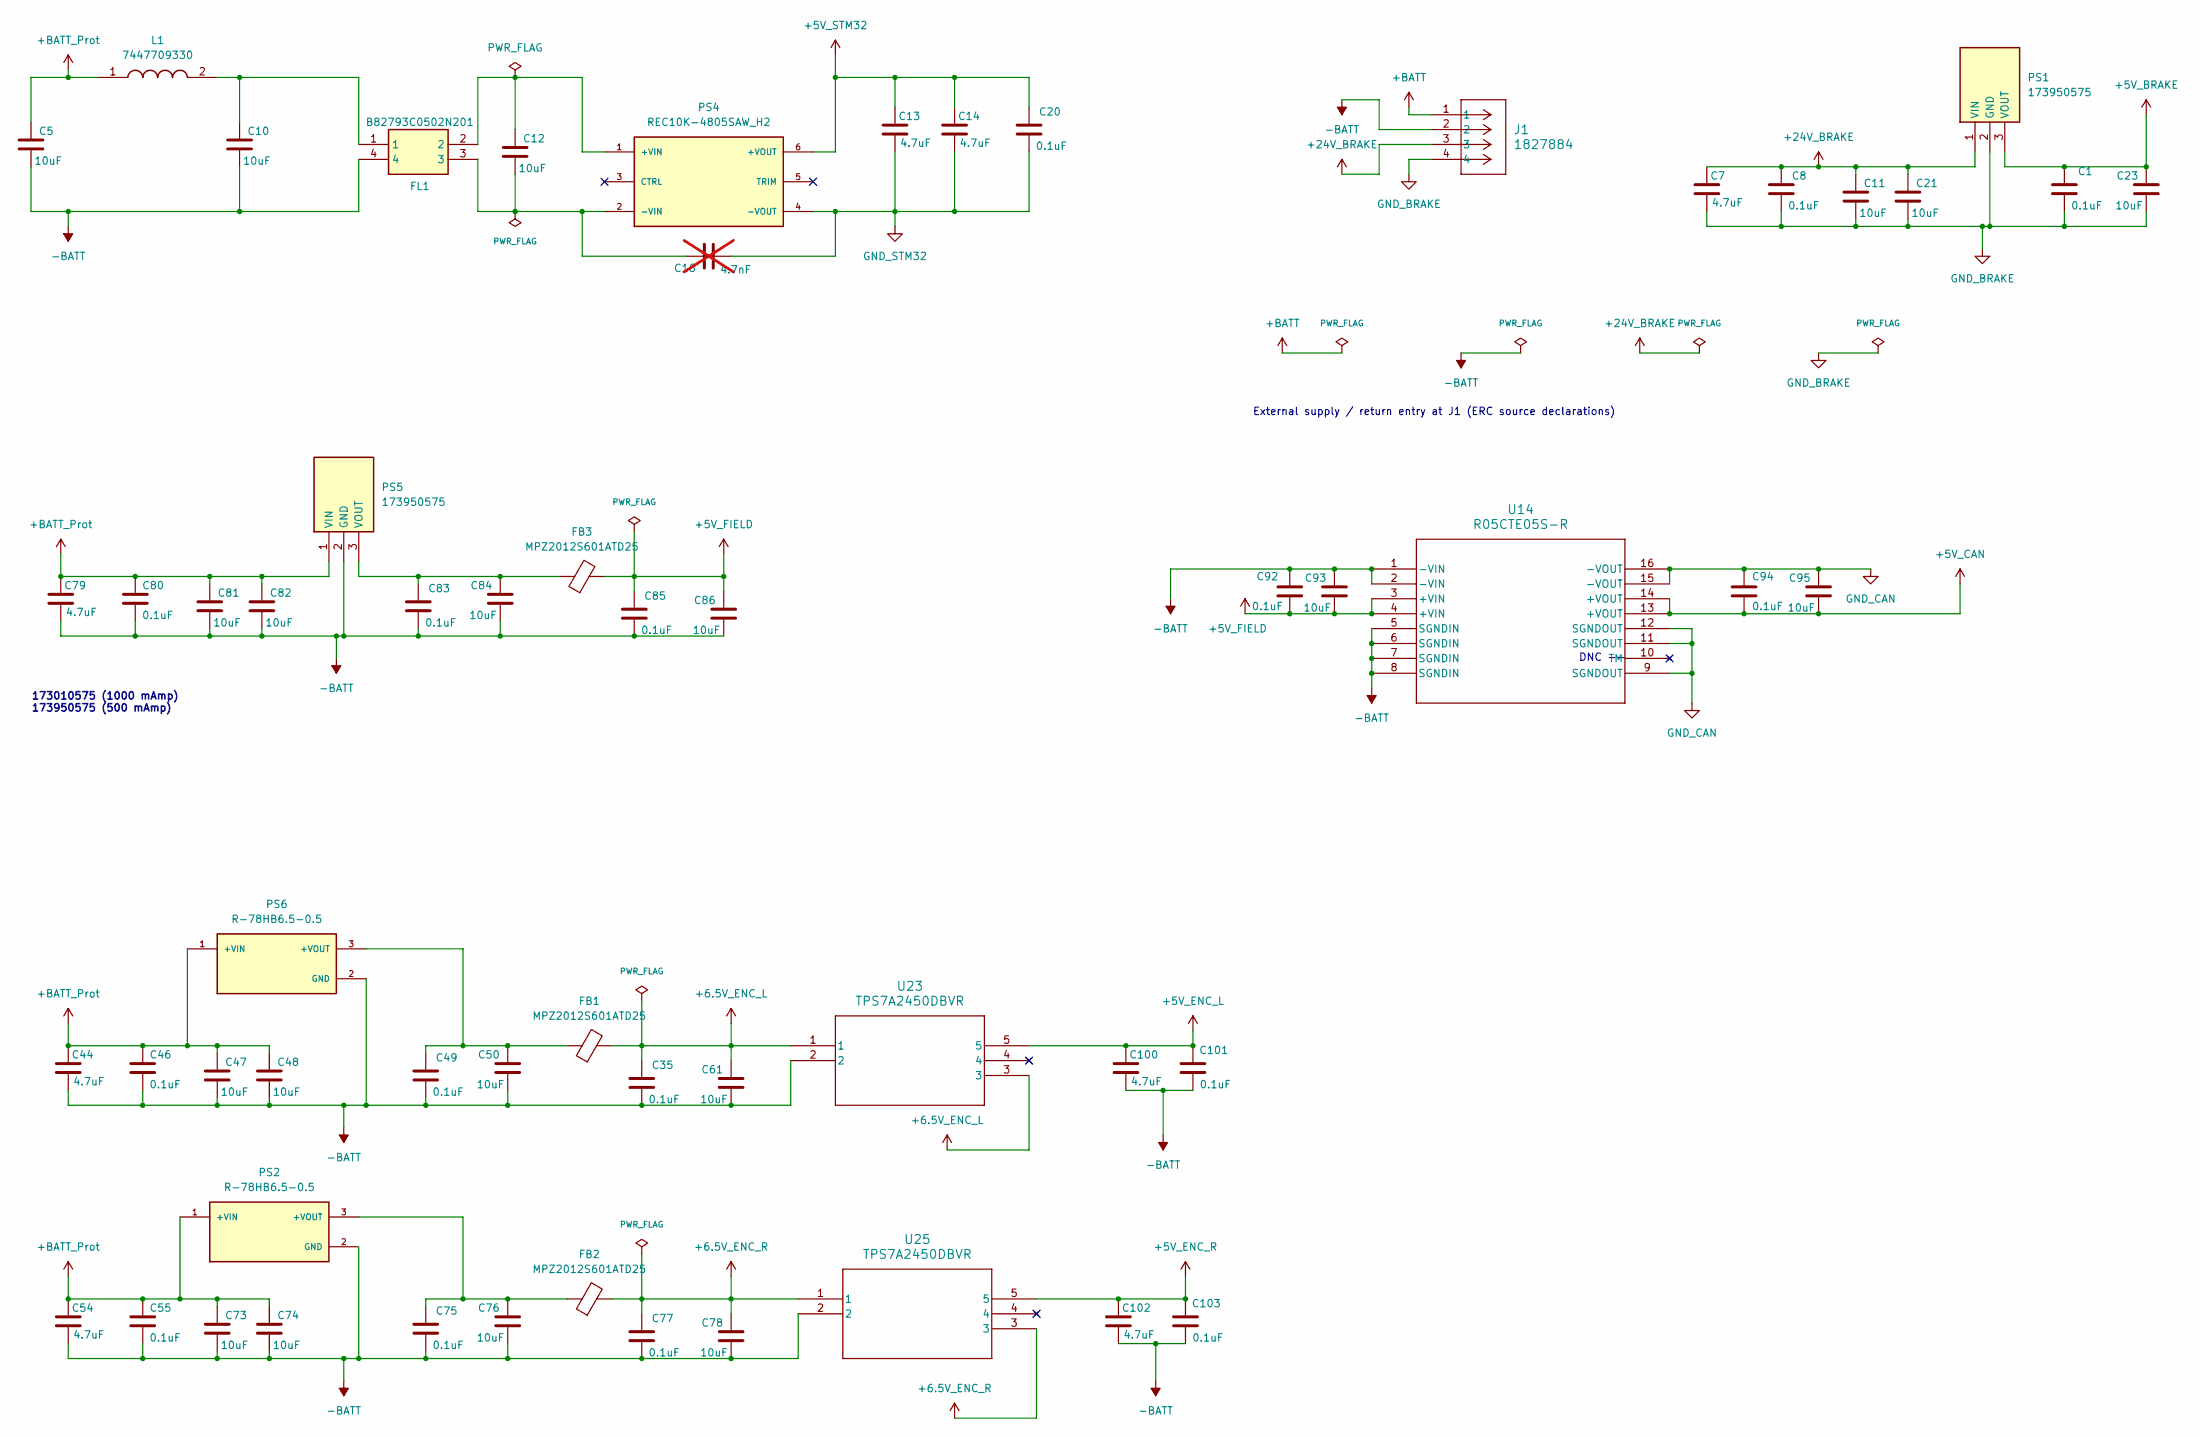
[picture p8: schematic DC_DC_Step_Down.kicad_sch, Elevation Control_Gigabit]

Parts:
C1, C8, C20, C35, C46, C49, C55, C75, C77, C80, C83, C85, C92, C94, C101, C103: 0.1uF; C_0805_2012Metric; MANUFACTURER_PART_NUMBER CL21B104KCFNNNE; LCSC C28233
C5, C10, C11, C12, C21, C47, C48, C73, C74, C81, C82: 10uF; C_2220_5750Metric; MANUFACTURER_PART_NUMBER FS55X106K101EHG; LCSC C153035
C7, C13, C14, C44, C54, C79, C100, C102: 4.7uF; C_1210_3225Metric; MANUFACTURER_PART_NUMBER CL32B475KCVZNWE; LCSC C17288249
C16: 4.7nF; C_2220_5750Metric; MANUFACTURER_PART_NUMBER GA355DR7GF472KW01L; LCSC C76897; not fitted
C23, C50, C61, C76, C78, C84, C86, C93, C95: 10uF; C_1210_3225Metric; MANUFACTURER_PART_NUMBER CL32B106KBJNFNE; LCSC C18739
FB1, FB2, FB3: MPZ2012S601ATD25; L_0805_2012Metric; MANUFACTURER_PART_NUMBER MPZ2012S601ATD25; LCSC C81034
FL1: B82793C0502N201; B82793C0104N201; Mouser Part Number 871-B82793C502N201
J1: 1827884; MANUFACTURER_PART_NUMBER 1827884
L1: 7447709330; WE-PD_1260_1245_1280_121054; Mouser Part Number 710-7447709330
PS1, PS5: 173950575; Mouser Part Number 710-173950575
PS2, PS6: R-78HB6.5-0.5; R_78HB6_5_0_5; PARTREV 5
PS4: REC10K-4805SAW_H2; PARTREV PRELIMINARY
U14: R05CTE05S-R; R05CTE05S; MANUFACTURER_PART_NUMBER R05CTE05S-CT; LCSC C6636280
U23, U25: TPS7A2450DBVR; MANUFACTURER_PART_NUMBER TPS7A2450DBVR; LCSC C2864436

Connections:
+5V_BRAKE: C1.2, C23.1, PS1.3 (VOUT); also elsewhere on the board
+5V_CAN: C94.2, C95.2, U14.13 (+VOUT), U14.14 (+VOUT); also elsewhere on the board
+5V_ENC_L: C100.1, C101.2, U23.5; also elsewhere on the board
+5V_ENC_R: C102.1, C103.2, U25.5; also elsewhere on the board
+5V_FIELD: C85.2, C86.1, C92.1, C93.2, FB3.2, U14.3 (+VIN), U14.4 (+VIN); also elsewhere on the board
+5V_STM32: C13.1, C14.1, C20.2, PS4.6 (+VOUT); also elsewhere on the board
+6.5V_ENC_L: C35.2, C61.1, FB1.2, U23.1, U23.3; also elsewhere on the board
+6.5V_ENC_R: C77.2, C78.1, FB2.2, U25.1, U25.3; also elsewhere on the board
+24V_BRAKE: C7.1, C8.2, C11.1, C21.1, J1.3, PS1.1 (VIN); also elsewhere on the board
+BATT: J1.1; also elsewhere on the board
+BATT_Prot: C5.1, C44.1, C46.2, C47.1, C48.1, C54.1, C55.2, C73.1, C74.1, C79.1, C80.2, C81.1, C82.1, L1.1, PS2.1 (+VIN), PS5.1 (VIN), PS6.1 (+VIN); also elsewhere on the board
-BATT: C5.2, C10.2, C35.1, C44.2, C46.1, C47.2, C48.2, C49.1, C50.2, C54.2, C55.1, C61.2, C73.2, C74.2, C75.1, C76.2, C77.1, C78.2, C79.2, C80.1, C81.2, C82.2, C83.1, C84.2, C85.1, C86.2, C92.2, C93.1, C100.2, C101.1, C102.2, C103.1, FL1.4, J1.2, PS2.2 (GND), PS5.2 (GND), PS6.2 (GND), U14.1 (-VIN), U14.2 (-VIN), U14.5 (SGNDIN), U14.6 (SGNDIN), U14.7 (SGNDIN), U14.8 (SGNDIN), U23.2, U25.2; also elsewhere on the board
GND_BRAKE: C1.1, C7.2, C8.1, C11.2, C21.2, C23.2, J1.4, PS1.2 (GND); also elsewhere on the board
GND_CAN: C94.1, C95.1, U14.9 (SGNDOUT), U14.11 (SGNDOUT), U14.12 (SGNDOUT), U14.15 (-VOUT), U14.16 (-VOUT); also elsewhere on the board
GND_STM32: C13.2, C14.2, C16.2, C20.1, PS4.4 (-VOUT); also elsewhere on the board
unnamed: C10.1, FL1.1, L1.2
unnamed: C75.2, C76.1, FB2.1, PS2.3 (+VOUT)
unnamed: C12.1, FL1.2, PS4.1 (+VIN)
unnamed: C12.2, C16.1, FL1.3, PS4.2 (-VIN)
unnamed: C83.2, C84.1, FB3.1, PS5.3 (VOUT)
unnamed: C49.2, C50.1, FB1.1, PS6.3 (+VOUT)

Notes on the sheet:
External supply / return entry at J1 (ERC source declarations)
DNC --
173010575 (1000 mAmp) 173950575 (500 mAmp)

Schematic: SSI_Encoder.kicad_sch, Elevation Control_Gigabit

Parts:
C2, C9, C56, C57, C62, C65, C99: 0.1uF; C_0805_2012Metric; MANUFACTURER_PART_NUMBER CL21B104KCFNNNE; LCSC C28233
C3, C17: 10uF; C_2220_5750Metric; MANUFACTURER_PART_NUMBER FS55X106K101EHG; LCSC C153035
C6, C58, C63, C64: 1uF; C_1206_3216Metric; MANUFACTURER_PART_NUMBER CL31B105KCHNNNE; LCSC C13832
D2, D3: TPD1E10B06DPYR; PARTREV G; LCSC C48260
J2, J4: DE9_Socket_MountingHoles; DSUB-9_Socket_Horizontal_P2.77x2.84mm_EdgePinOffset7.70mm_H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; MANUFACTURER_PART_NUMBER 5747844-4; LCSC C305941
Q6, Q7: 2N7002KQ-7; SOT-23; MANUFACTURER_PART_NUMBER 2N7002KQ-7; LCSC C111971
R2, R4: 120; R_0805_2012Metric; MANUFACTURER_PART_NUMBER RC0805FR-07120RL; LCSC C114245
R39, R40: 10K; R_0805_2012Metric; MANUFACTURER_PART_NUMBER RC0805FR-0710KL; LCSC C84376
R59, R60: 2.2K; R_0805_2012Metric; MANUFACTURER_PART_NUMBER RC0805FR-072K2L; LCSC C114561
R61, R62: 47K; R_0805_2012Metric; MANUFACTURER_PART_NUMBER RC0805FR-0747KL; LCSC C126351
U3, U6, U8, U9: TPD2E2U06QDBZRQ1; SOT95P237X95-3N; MANUFACTURER_PART_NUMBER TPD2E2U06QDBZRQ1; LCSC C488151
U7, U16: ISO1432DWR; MANUFACTURER_PART_NUMBER ISO1432DWR; LCSC C2672372
U22: SN74LVC2G07DCKR(UMW); SN74LVC2G07; MANUFACTURER_PART_NUMBER SN74LVC2G07DCKR(UMW); LCSC C7394023
U26, U27: TPD1E10B09DPYR; MANUFACTURER_PART_NUMBER TPD1E10B09DPYR; LCSC C88031

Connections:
+3V3_STM32: C6.1, C56.2, C64.1, C65.2, R39.2, R40.2, U7.1 (VCC1), U7.5 (DE), U16.1 (VCC1), U16.5 (DE); also elsewhere on the board
+5V_ENC_L: C57.2, C58.1, R59.1, R61.1, U7.16 (VCC2); also elsewhere on the board
+5V_ENC_R: C62.2, C63.1, R60.1, R62.1, U16.16 (VCC2); also elsewhere on the board
+5V_FIELD: C99.2, U22.5 (VCC); also elsewhere on the board
+6.5V_ENC_L: C2.2, C17.1, J4.1, U26.1 (K); also elsewhere on the board
+6.5V_ENC_R: C3.1, C9.2, J2.1, U27.1 (K); also elsewhere on the board
-BATT: C2.1, C3.2, C9.1, C17.2, C57.1, C58.2, C62.1, C63.2, C99.1, D2.2, D3.2, J2.0 (PAD), J2.2, J2.9, J4.0 (PAD), J4.2, J4.9, Q6.2 (S), Q7.2 (S), U3.3 (GND), U6.3 (GND), U7.9 (GND2), U7.15 (GND2__1), U8.3 (GND), U9.3 (GND), U16.9 (GND2), U16.15 (GND2__1), U22.2 (GND), U26.2 (A), U27.2 (A); also elsewhere on the board
/SSI_Encoder/LH_SSI_CLK: R39.1, U7.6 (D); also elsewhere on the board
/SSI_Encoder/LH_SSI_DATA: U7.3 (R); also elsewhere on the board
/SSI_Encoder/RH_SSI_CLK: R40.1, U16.6 (D); also elsewhere on the board
/SSI_Encoder/RH_SSI_DATA: U16.3 (R); also elsewhere on the board
GND_STM32: C6.2, C56.1, C64.2, C65.1, U7.2 (GND1), U7.4 (~RE), U7.8 (GND1__1), U16.2 (GND1), U16.4 (~RE), U16.8 (GND1__1); also elsewhere on the board
LH_ENC_CLK_N: J4.7, U6.1 (IO1), U7.12 (Z)
LH_ENC_CLK_P: J4.3, U6.2 (IO2), U7.11 (Y)
LH_ENC_DATA_N: J4.6, R2.1, U3.1 (IO1), U7.13 (B)
LH_ENC_DATA_P: J4.4, R2.2, U3.2 (IO2), U7.14 (A)
LH_ENC_POS_PRESET: U22.1 (1A); also elsewhere on the board
unnamed: D3.1, J4.5, Q6.3 (D), R59.2
unnamed: Q6.1 (G), R61.2, U22.6 (1Y)
unnamed: D2.1, J2.5, Q7.3 (D), R60.2
unnamed: Q7.1 (G), R62.2, U22.4 (2Y)
RH_ENC_CLK_N: J2.7, U9.1 (IO1), U16.12 (Z)
RH_ENC_CLK_P: J2.3, U9.2 (IO2), U16.11 (Y)
RH_ENC_DATA_N: J2.6, R4.1, U8.1 (IO1), U16.13 (B)
RH_ENC_DATA_P: J2.4, R4.2, U8.2 (IO2), U16.14 (A)
RH_ENC_POS_PRESET: U22.3 (2A); also elsewhere on the board

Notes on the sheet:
STM32 encoder data output
STM32 encoder data input
STM32 encoder clock output

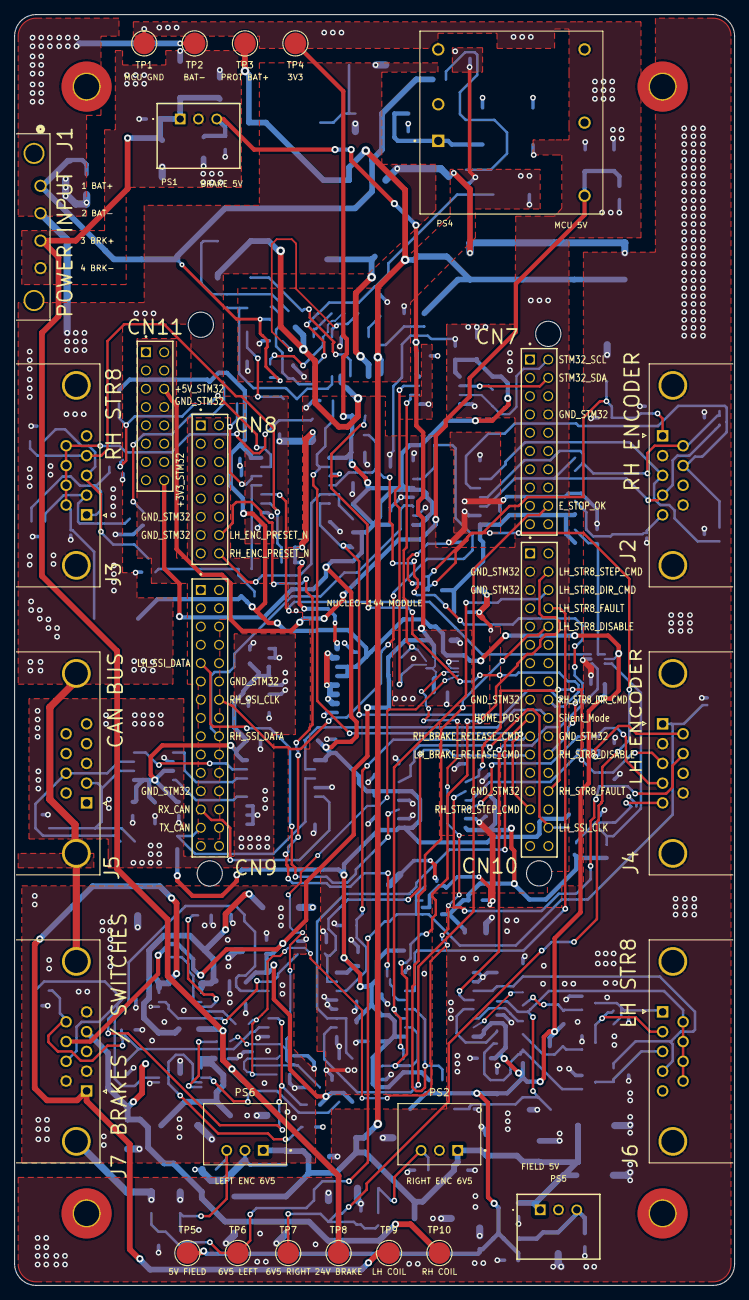
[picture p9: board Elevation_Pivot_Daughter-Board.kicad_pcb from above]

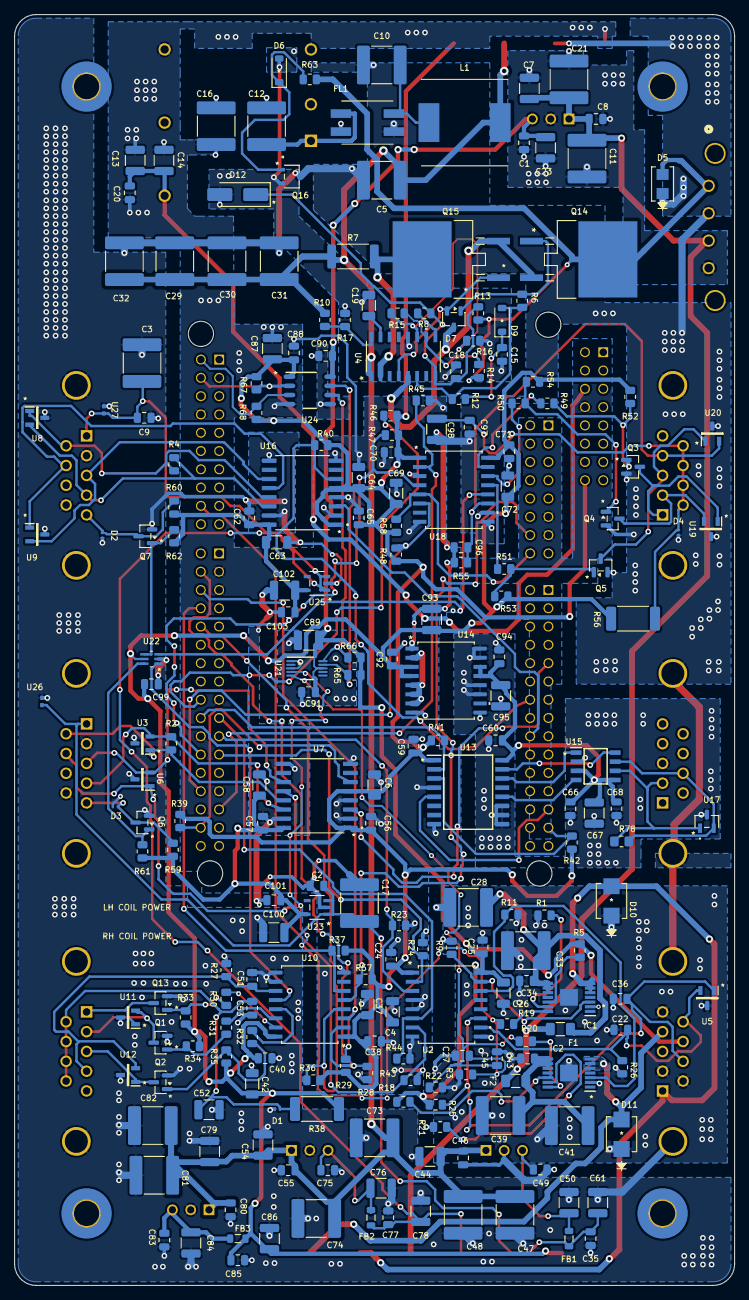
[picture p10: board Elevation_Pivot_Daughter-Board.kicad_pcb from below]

Board: 4 copper layers, 100.0 x 176.5 mm, 263 parts (228 on the bottom side), 118 nets.

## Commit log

2026-10-03 Initialize pivot daughter-board redesign baseline
    [ADS1115.kicad_sch, Brakes.kicad_sch, DC_DC_Step_Down.kicad_sch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]
2026-10-03 Document dual-encoder power and thermal redesign
2026-10-03 Correct pivot encoder and raw battery topology
2026-10-03 Redesign schematic for dual motor encoders
    [ADS1115.kicad_sch, Brakes.kicad_sch, DC_DC_Step_Down.kicad_sch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]
